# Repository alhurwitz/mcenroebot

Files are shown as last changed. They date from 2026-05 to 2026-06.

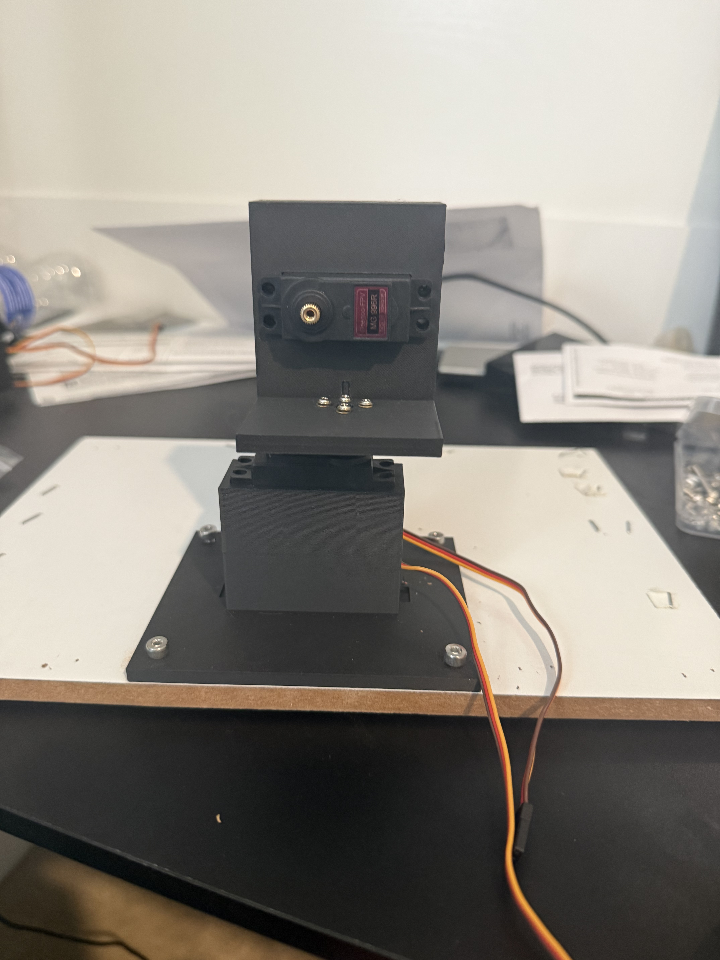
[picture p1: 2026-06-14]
docs/images/IMG_5126.jpg

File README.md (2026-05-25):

# McEnroe — Ping-Pong Robot (V2)

A hobby ping-pong robot. **V2** is the *aim-and-swat* phase: a 3-axis turret that orients a paddle at an incoming ball
and fires an open-loop swing to return it.

This repository holds the V2 control software. It runs against mocks on a laptop and on real hardware on a Raspberry Pi
4.

---

## How it works

A single webcam tracks the ball. Depth is recovered monocularly from the ball's apparent radius. A short rolling buffer
of observations is fit to a 3D ballistic trajectory, which predicts where (and when) the ball will cross the strike
plane. Two servos aim the paddle's sweep plane at that point; a brushless motor swings the paddle through it on a fixed
timing envelope.

```
 webcam ──► tracker ──► predictor ──► aim controller ──► servos (J1 yaw, J2 pitch)
                          │
                          └─────────► swing controller ──► BLDC (J3 swing)
```

### Hardware

| Part | Role |
|---|---|
| Raspberry Pi 4 (Bookworm, Python 3.11) | Deploy target |
| Adafruit PCA9685 16-channel PWM HAT | I²C `0x40` — pan=ch0, tilt=ch1, BLDC ESC=ch2 |
| 2× MG996R servos | J1 yaw, J2 pitch (paddle orientation) |
| A2212 1000 KV brushless motor + ESC | J3 paddle swing |
| 3S LiPo | BLDC supply |
| HAT 5V/3A PSU | Servo supply |
| Logitech webcam (`/dev/video0`) | Ball tracking (2D + monocular depth) |

### Coordinate frame

- **Origin:** J1 yaw axis, at J2 pitch pivot height.
- **+X** forward (toward the ball), **+Y** left (viewed from above), **+Z** up.
- Meters internally; degrees at servo I/O; seconds for time.

---

## Status

| Component | State |
|---|---|
| `aim/` (AimController, Position3D, ServoAngles, TurretGeometry) | ✅ Wave 1 |
| `clock/` (Clock, SystemClock, FakeClock) | ✅ Wave 1 |
| `camera/` (CameraIntrinsics, pixel_to_ray) | ✅ Wave 1 |
| `ball/` (BallObservation/State/Prediction, BallRadiusDepth) | ✅ Wave 1 |
| `drivers/servo/`, `drivers/bldc/` (Protocols + PCA9685 + Mocks) | ✅ Wave 1 |
| `predictor/` (TrajectoryPredictor, weighted ballistic fit) | ✅ Wave 2 |
| `swing/` (SwingProfile + SwingController, open-loop envelope) | ✅ Wave 2 |
| `calibrate/` (EscCalibrator one-shot routine) | ✅ Wave 2 |
| `coordinator/` (RallyCoordinator, full pipeline) | ✅ Wave 3 |
| Pi deployment | ⏳ Hardware bring-up |

See [`docs/implementation-plan.md`](docs/implementation-plan.md) for the wave-by-wave build schedule and
[`docs/V2_PLAN.md`](docs/V2_PLAN.md) for the original design.

---

## Quickstart (laptop development)

Prereqs: `uv` (replaces `pip`/`venv`).

```bash
uv sync                          # install runtime + dev deps into .venv
uv run pre-commit install --hook-type pre-commit --hook-type commit-msg
uv run pytest                    # run the full suite with coverage
uv run python -m mcenroebot.aim  # print aim-controller sanity demo
```

### Common commands

```bash
uv run pytest                                       # full suite (coverage runs automatically)
uv run pytest -q                                    # quiet
uv run pytest tests/test_aim.py::TestAimControllerCompute::test_directly_forward_gives_neutral_pose
uv run pytest -m unit                               # by marker: unit / integration / perf / adapter

uv run mypy src/                                    # strict, with pydantic plugin
uv run ruff check src/                              # lint
uv run ruff format src/                             # format

uv add <package>                                    # add a runtime dep (never edit pyproject.toml by hand)
uv add --dev <package>                              # dev-only
uv add --optional pi <package>                      # Pi-only optional extra
```

Pre-commit runs ruff (lint + format), mypy, detect-secrets, and commitizen on commit; pytest runs on **pre-push**.

---

## Pi deployment

Deferred until Wave 3 lands. The high-level steps:

```bash
# On the Pi
cd ~/mcenroebot
uv sync --extra pi               # pulls adafruit-blinka, pca9685, servokit
uv run python -m mcenroebot.calibrate   # one-shot ESC arming
uv run python -m mcenroebot.coordinator # rally loop against live webcam
```

The real Adafruit drivers are imported **lazily** inside the driver constructors so the package still imports on a Mac (
where those libraries aren't installed).

---

## Coding standards

These are the non-negotiable ones. See [`CLAUDE.md`](CLAUDE.md) for the full set.

- **OOP everywhere.** Public API is classes; no bare module-level functions.
- **Pydantic v2 frozen models** (`BaseModel` + `ConfigDict(frozen=True)`) for every value object. No `@dataclass`. Range
  checks via `@field_validator`. Pydantic constructors are **keyword-only** at every call site.
- **Hardware abstraction.** Every GPIO-touching driver has a `Protocol` interface and a paired `Mock<Name>Driver`.
  Higher-level code is tested against mocks only.
- **Type hints everywhere**; `mypy --strict` must pass.
- **Coverage ≥85%** (enforced); aim ≥95% on pure-math modules.

---

## Project layout

```
src/mcenroebot/        # package source (src-layout)
  aim.py               # implemented
  ...                  # see docs/implementation-plan.md for the rest
tests/                 # pytest, mirrors src/mcenroebot/ structure
docs/
  implementation-plan.md  # actionable wave-by-wave plan
  V2_PLAN.md              # original design + module specs
CLAUDE.md              # guidance for Claude Code sessions
pyproject.toml         # ruff, mypy strict, pytest config, coverage floor
```

---

## Gitflow

`main` ← `develop` ← `feature/*`. Conventional commits enforced by commitizen on commit-msg (`feat(scope):`,
`fix(scope):`, `refactor(scope):`, `test(scope):`, `chore:`, `docs:`).

Current state: `feature/aim` holds the aim module and pydantic v2 refactor; it will merge to `develop`, then
`feature/v2-control` will be cut for Waves 1–3.

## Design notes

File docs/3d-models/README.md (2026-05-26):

# McEnroe V2 — Arm Design ("Aim-and-Swat" Turret)

## The pivot

The original `PROJECT_PLAN.md` called for a dual-wheel ball launcher. This is the
arm-based alternative AJ asked for in V2: a real paddle on a swinging arm, aimed
by a 2-DOF turret. It's harder than a launcher but it's the McEnroe-y answer —
the robot actually *hits* the ball with a paddle instead of spitting it out of a
nozzle.

## Architecture

Three independent axes:

1. **Yaw** (J1) — base rotation. Aims the strike plane left/right.
2. **Pitch** (J2) — shoulder tilt. Aims up/down and sets approach angle.
3. **Swing** (J3) — fast paddle stroke. Open-loop, fired at a predicted T0.

J1 and J2 are MG996R metal-gear servos (slow-but-accurate aiming).
J3 is a brushless motor (A2212 1000KV from the existing BOM) — used for raw
swing speed, not closed-loop position control.

The control loop:
1. Camera tracks ball → trajectory predictor estimates contact point + time.
2. J1 + J2 move to point the strike plane at the predicted contact (settles
   well before T0).
3. At T0 − swing_latency, fire J3 throttle. Paddle sweeps through the plane.
4. Ball gets hit (in theory). Trash talk plays regardless of outcome.

## Why not a full 6-DOF arm

A real arm with closed-loop joint control needs harmonic drives or high-Kv
servos that cost more than the rest of the BOM combined. We don't have the
torque budget on hobby servos to drive a 0.25m arm fast enough. The compromise:
slow aiming + dumb fast swing.

## Honest limitation: paddle tip speed

A2212 1000KV at full throttle on 3S is ~11,000 RPM — way too fast for direct
drive on a paddle. At 10–20% throttle for ~150ms we get a 90° sweep with paddle
tip speed around 2–3 m/s. Recreational ping pong returns want 4–8 m/s tip
speed. So this first pass will probably hit the ball but won't drive it back
hard. That's fine — first iteration. Next iteration options:

- Gear down a higher-torque BLDC (or use a sensored brushless gimbal motor).
- Use a beefier outrunner (e.g. 2814 700KV) on a 4S pack.
- Add a torsion spring that pre-loads the arm and gets released by a servo.

## Parts (in this folder)

| File | What it is | Material | ~Print time |
|---|---|---|---|
| `01_base_plate.stl` | Bolts to a weighted base, mounts the yaw servo | PETG+ | ~2h |
| `02_yaw_bracket.stl` | Rides on yaw servo horn, mounts pitch servo | PETG+ | ~2h |
| `03_pitch_bracket.stl` | Rides on pitch servo horn, holds the BLDC + bearings | PETG+ | ~3h |
| `04_swing_arm.stl` | Bolts to BLDC shaft, holds the paddle clamp | PETG+ | ~1.5h |
| `05_paddle_clamp.stl` | Two halves that clamp a paddle blade | PLA matte | ~1h |

Use **PETG+** for everything load-bearing (PLA creeps under sustained torque).
Paddle clamp is fine in PLA since it's only loaded in compression.

## How parts mate

```
       [ paddle blade ]
              │
       [ paddle clamp ]   ← M3 × 4, pinches paddle blade
              │
       [ swing arm ]      ← M3 set-screw on BLDC shaft
              │
        ( A2212 BLDC )
              │
       [ pitch bracket ]  ← 608 bearings flank the motor
              │
        ( MG996R J2 )
              │
       [ yaw bracket ]
              │
        ( MG996R J1 )
              │
       [ base plate ]
              │
        weighted base (table-clamp, sandbag, anything heavy)
```

## Regenerating parts

All STLs are generated by `generate_parts.py` in this folder. Tweak constants
at the top, re-run, get new STLs:

```bash
cd 3d-models
python3 generate_parts.py
```

## Print settings (Bambu Studio, P2S)

- Nozzle: 0.4mm
- Layer height: 0.20mm (0.16 if you're feeling patient)
- Walls: 4 perimeters
- Infill: 40% gyroid for structural parts, 15% for paddle clamp
- Supports: tree, only on overhangs >55°. Most parts designed to print
  flat-side-down with no supports needed.
- Brim: 5mm on the swing arm (long thin part, wants to lift)

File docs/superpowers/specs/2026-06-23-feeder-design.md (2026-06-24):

# McEnroe V4 Feeder — Design Spec

Date: 2026-06-23
Status: Approved (brainstorming → implementation)
Branch: `feature/v4-feeder` (cut from `develop`)

This spec reconciles [`docs/V4_PLAN.md`](../../V4_PLAN.md) (mechanism source of truth) and
[`docs/v4-implementation-plan.md`](../../v4-implementation-plan.md) (build checklist) with the
**actual** state of the codebase as of 2026-06-23. Where the two plan docs disagree with reality,
this spec is authoritative for the software work.

---

## 1. Goal

Pivot McEnroe from an aim-and-swat / return-rally robot to a **feeder**: a spin/aim ball machine
that serves balls with controlled speed and spin to chosen court locations, with a closed recycle
loop (catch net → trough → auger → hopper → escapement → launch wheels).

**Explicitly out of scope** (the hard rally slice): incoming-ball 3D tracking, strike-plane
prediction, sub-100 ms timing. The feeder is a periodic scheduler driving actuators — not a
real-time vision control loop.

---

## 2. Codebase reconciliation (plan vs. reality)

A fresh inventory of `src/mcenroebot/` found the repo already contains the **entire V3 rally
stack**, not just the `aim/` slice the old CLAUDE.md describes. Findings that change the plan:

| Plan assumption | Reality | Resolution |
| --- | --- | --- |
| Reuse `aim/`, `clock/`, `camera/`, `drivers/servo/`, `drivers/bldc/` | All present and built | Reuse as-is |
| `drivers/bldc/` "extends `esc_arm`" | No `esc_arm`; ESC arming lives in `calibrate/EscCalibrator` (`calibrate/esc.py`) | `launch/` throttle helper + Wave 5 reuse `calibrate/EscCalibrator`; drop `esc_arm` references |
| Shelved: `predictor/`, `swing/`, `ball/`, `coordinator.RallyCoordinator` | All present and fully built | **Archive** to `_shelved/` (see §4) |
| Python floor `>=3.13`, reconcile to 3.11 before Pi | `pyproject.toml` already `requires-python = ">=3.11"` | **Resolved** — drop this open question |
| New: `launch/`, `drill/`, `drivers/feeder/`, `drivers/lift/`, `player/` | All correctly absent | Build per waves |
| Branch `feature/v4-feeder` from `develop` | Currently on `feature/v4`; `develop` exists but is behind | Cut `feature/v4-feeder` from `develop`, carry plan docs forward (see §3) |

Existing reused packages (do not modify): `aim/`, `clock/`, `camera/`, `calibrate/`,
`drivers/servo/`, `drivers/bldc/`.

---

## 3. Branch setup

- Cut `feature/v4-feeder` from `develop`.
- The V4 plan docs (`docs/V4_PLAN.md`, `docs/v4-implementation-plan.md`) and the untracked
  `docs/3d-models/generate_feeder_parts.py` currently live on `feature/v4`, not `develop`. Carry
  these files forward onto `feature/v4-feeder` so the plan travels with the work. The diff against
  `develop` is shown to the user before anything lands.
- Only feeder-relevant content is brought across; unrelated `feature/v4` commits are not merged.

---

## 4. Archive the V3 rally stack

Move the V3-only modules to `src/mcenroebot/_shelved/` (underscore prefix = clearly inactive, not
part of the public import surface). Verified safe: **nothing in the active/reused set imports the
V3-only set** — only `coordinator/rally.py` references `ball`/`predictor`/`swing`, and it moves too.

| Move from | Move to |
| --- | --- |
| `src/mcenroebot/ball/` | `src/mcenroebot/_shelved/ball/` |
| `src/mcenroebot/predictor/` | `src/mcenroebot/_shelved/predictor/` |
| `src/mcenroebot/swing/` | `src/mcenroebot/_shelved/swing/` |
| `src/mcenroebot/coordinator/rally.py` + `coordinator/__main__.py` | `src/mcenroebot/_shelved/rally/` |
| `tests/test_ball/`, `tests/test_predictor/`, `tests/test_swing/` | `tests/_shelved/...` |
| `tests/test_coordinator/test_rally.py` | `tests/_shelved/test_rally/...` |

Rules for the move:
- Rewrite internal imports within the moved set to `mcenroebot._shelved.*`. `ball/depth.py` keeps
  importing `mcenroebot.camera` (camera stays active; archive→active dependency is fine).
- **Tests move with their code and keep passing** so the 85% coverage floor holds across the move.
- `src/mcenroebot/__init__.py` keeps exporting only the aim symbols (already the case) — no
  `_shelved` symbols are re-exported at the top level.
- After the move, `coordinator/` holds only `__init__.py`, rewritten to export nothing (`__all__ =
  []`) until Wave 4 adds `FeederCoordinator`. The package is then ready to host `feeder.py`.
- `_shelved/__init__.py` documents the package as inactive V3 code, retained for reference.
- This is committed **first** on `feature/v4-feeder`, before any new feeder code, so the active
  surface is unambiguous. Phase gate: `uv run pytest` green, `uv run mypy src/` clean.

---

## 5. Conventions (mandatory — copy from `aim/` and `drivers/servo/`)

- Every component is a **package** (`__init__.py` + files split by responsibility: `protocol.py`,
  real impl, `mock.py`, `value_objects.py`, `controller.py`, `__main__.py` demo). Re-export the
  public API via `__init__.py`.
- Value objects are **pydantic v2 `BaseModel`, `frozen=True`**, keyword-only at all call sites.
  Range checks in `@field_validator`. Tests assert `ValidationError`, not `ValueError`.
- Controllers are **stateless apart from injected config**. Out-of-envelope → return `None`, don't raise.
- Every GPIO-touching driver: a `Protocol`, a real impl with Adafruit/GPIO libs **lazy-imported
  inside `__init__`**, and a `Mock<Name>Driver` that records calls. Higher layers test against
  mocks; real drivers are `@pytest.mark.integration`, skipped off-Pi.
- Conventional commits (`feat(scope):` …), one logical commit per package.
- Pi-only deps go in `[project.optional-dependencies] pi`, added via `uv add --optional pi`.

### Coordinate / spin conventions (used by `launch/`)

- Reuse the V2 frame: `+X` forward (toward the player), `+Y` left, `+Z` up. Meters internally,
  degrees for servo I/O, seconds for time.
- **Topspin > 0** (ball top rotates toward the player). Backspin < 0.
- `head_roll_deg`: rotation of the two-wheel head about the shot axis. `0°` = spin axis horizontal
  → pure top/backspin. `90°` = spin axis vertical → pure sidespin. General angle → mix.

---

## 6. Module architecture & waves

```
        clock/ (reuse)         camera/ (reuse, vision phase only)
           │                        │
           │                        ▼
           │                   player/ (NEW, Wave 6)
           │                        │
   ┌───────┴───────────┐            │
   ▼                   ▼            ▼
drivers/feeder/   drivers/lift/   drill/ ──── AimStrategy (Protocol)
   │                   │            │           ├─ FixedPatternStrategy (Wave 3)
   │                   │            │           └─ VisionPlacementStrategy (Wave 6)
   │                   │            ▼
   │                   │         launch/ (NEW, pure math)  aim/ (reuse)
   │                   │            │                         │
   └───────────────────┴───────┐    │   drivers/bldc/ (reuse) │  drivers/servo/ (reuse)
                               ▼    ▼            │            ▼            │
                          coordinator.FeederCoordinator (NEW) ────────────┘
```

### Wave 1 — `launch/` (pure math, no hardware) — **this session**

The analog of `aim/`. Built first; everything depends on its value objects. Target **≥95% coverage**.

| File | Contents |
| --- | --- |
| `value_objects.py` | `ShotSpec`, `WheelCommand`, `LaunchGeometry`, `ThrottleMap` |
| `controller.py` | `LaunchController` |
| `__main__.py` | demo: print `WheelCommand` for a few `ShotSpec`s |
| `__init__.py` | re-export public API |

```python
class ShotSpec(BaseModel):          # frozen
    speed_mps: float                # desired ball exit speed; > 0
    spin_rad_s: float               # signed magnitude; + = topspin at roll 0
    spin_axis_deg: float            # head roll: 0 = top/back, 90 = side; [0, 360)

class WheelCommand(BaseModel):      # frozen
    top_rpm: float                  # >= 0
    bottom_rpm: float               # >= 0
    head_roll_deg: float            # [0, 180] servo range (validate)

class LaunchGeometry(BaseModel):    # frozen; injected config, mirrors TurretGeometry
    wheel_diameter_m: float         # e.g. 0.055
    ball_radius_m: float = 0.02
    grip_efficiency: float = 0.85   # eta: ball speed / mean surface speed; calibrated
    spin_efficiency: float = 0.85   # eta_spin; calibrated
    max_wheel_rpm: float            # from no-load BLDC rpm at deploy voltage

class ThrottleMap(BaseModel):       # frozen; calibrated rpm <-> ESC throttle [0,1]
    rpm_at_full_throttle: float     # measured rpm at throttle = 1.0
    # linear v1 model: throttle = rpm / rpm_at_full_throttle, clamped [0,1]
```

`LaunchController.compute(spec) -> WheelCommand | None`:

```
mean_surface = speed_mps / grip_efficiency
diff_surface = 2 * ball_radius_m * spin_rad_s / spin_efficiency
u_top    = mean_surface + diff_surface / 2
u_bottom = mean_surface - diff_surface / 2
rpm(u)   = u * 60 / (pi * wheel_diameter_m)
top_rpm, bottom_rpm = rpm(u_top), rpm(u_bottom)
head_roll_deg = spin_axis_deg folded into [0, 180]   # 180° head symmetry
```

Return `None` (out of envelope) when `u_top < 0` or `u_bottom < 0` (spin too high for the speed),
or either rpm `> max_wheel_rpm`. Also provide
`LaunchController.throttles(cmd, throttle_map) -> tuple[float, float]` converting a `WheelCommand`
to two ESC throttles for the bldc layer.

Tests `tests/test_launch/`:
- Zero spin → `top_rpm == bottom_rpm == rpm(speed/grip_efficiency)`.
- Positive spin → `top_rpm > bottom_rpm`; negative → reversed.
- Round-trip: pick `(u_top, u_bottom)`, derive the `ShotSpec` they'd produce, confirm `compute`
  recovers those wheel speeds within `1e-6`.
- Spin too high for speed → `None` (not a negative rpm). rpm over `max_wheel_rpm` → `None`.
- `head_roll_deg` folds to `[0, 180]`; `WheelCommand` raises `ValidationError` outside it.
- `ThrottleMap` clamps to `[0, 1]`. Frozen-ness of all four value objects.

Commit: `feat(launch): add LaunchController + ShotSpec/WheelCommand/LaunchGeometry value objects`

### Wave 2 — `drivers/feeder/` + `drivers/lift/` (mock-tested, real gated)

- `drivers/feeder/` (escapement): `FeederDriver` Protocol (`set_rate(balls_per_min)`, `stop()`,
  `fire()` — v1 `fire()` raises `NotImplementedError`), `Pca9685FeederDriver` (CR servo on a
  PCA9685 channel; lazy `adafruit_servokit`; rate→throttle linear factor), `MockFeederDriver`.
- `drivers/lift/` (auger): `LiftDriver` Protocol (`set_duty([0,1])`, `off()`), `HopperSensor`
  Protocol (`is_full()`), `Pca9685LiftDriver` (PWM → MOSFET gate, lazy import), `MockLiftDriver`,
  `GpioHopperSensor` (lazy `RPi.GPIO`), `MockHopperSensor`.
- Tests: rate/duty monotonic + clamped; `stop()`/`off()` → 0; mocks record call order; lazy
  imports succeed off-Pi; real smoke tests `@integration`.
- Document the new PCA9685 channel map (two wheel ESCs, roll servo, CR-servo feeder) in `CLAUDE.md`,
  mirroring the existing `pan=ch0, tilt=ch1, ESC=ch2` line.

Commit: `feat(drivers): add feeder (escapement) and lift (auger) drivers with mocks`

### Wave 3 — `drill/` (no hardware)

- `AimStrategy` Protocol (`next_target(ctx) -> Position3D`), `Shot` value object (`spec`, `target`,
  `delay_s`), `FixedPatternStrategy` (patterns: `static`, `oscillate`, `random`, `figure8`; pure
  function of shot index + RNG seed), `Drill.shots(n) -> Iterator[Shot]` (stateless config +
  injected seeded RNG).
- Tests: targets within table bounds; fixed seed → identical sequence; cadence respected; figure-8
  quadrant order; frozen value objects.

Commit: `feat(drill): add Drill engine, AimStrategy Protocol, FixedPatternStrategy`

### Wave 4 — `coordinator/feeder.py` (no hardware)

`FeederCoordinator` (new file in `coordinator/`, must not import `_shelved.*`). Constructor injects
`drill`, `launch` + `launch_geometry` + `throttle_map`, `aim` (`AimController`), `servo` (pan/tilt),
`head_roll` servo, `wheel_top`/`wheel_bottom` BLDC, `feeder`, `lift`, `clock`, optional `hopper`.

`async run(n)` per shot: next `Shot` → `launch.compute` (skip+log if `None`) → `aim.compute`
(skip+log if unreachable) → command head-roll + pan/tilt + wheel throttles → settle → release ball
(`set_rate` v1) → run lift (`off()` if `hopper.is_full()`) → `clock.sleep(delay_s)`. On exit
(try/finally): wheels throttle 0, `feeder.stop()`, `lift.off()`.

Tests (mock everything + `FakeClock`): happy path ordered calls; `launch.compute None` skips shot;
`aim.compute None` skips shot; hopper full → `lift.off()`; clean shutdown on normal end and on
exception.

Phase gate: `uv run pytest` green, `uv run mypy src/` clean, coverage ≥85% (`launch/` ≥95%); a
simulated 100-shot drill issues correct ordered commands for 100/100 cases.

Commit: `feat(coordinator): add FeederCoordinator wiring drill -> launch + aim + feeder + lift`

### Wave 5 — calibration scripts + first live feed (hardware)

PEP-723 standalone scripts under `scripts/` (inline metadata, own deps — same pattern as
`scripts/calibrate_camera.py`):
- `scripts/calibrate_feeder.py` — sweep CR-servo throttle, count balls / 60 s, fit
  `balls_per_min ↔ throttle`.
- `scripts/calibrate_launch.py` — grid of `(top_rpm, bottom_rpm)`, measure landing distance (+spin
  if video available), back out `grip_efficiency`, `spin_efficiency`, `rpm_at_full_throttle`; writes
  JSON loadable via `LaunchGeometry.model_validate_json`.

Bring-up on the Pi (`uv sync --extra pi`): arm both ESCs via `calibrate/EscCalibrator` (once per
wheel) → run calibration scripts → run `FeederCoordinator` with a `static` `FixedPatternStrategy`
at low rpm.

Phase gate: 20 consecutive balls to a chosen spot at controlled speed, no jam/double-feed; auger
keeps hopper non-empty over a 5-minute run.

### Wave 6 — vision placement (optional, hardware)

`player/` package: `PlayerDetector` Protocol (`detect(frame) -> PlayerPosition | None`),
`PlayerPosition` value object (`side_offset_m`, `confidence`), `SimpleBlobDetector` (background
subtraction / contour centroid over the `camera/` frame source), `MockPlayerDetector`.
`drill.VisionPlacementStrategy` implements `AimStrategy`: aim next ball to the open side; low
confidence → fall back to a fixed pattern. Drops in behind the existing `AimStrategy` Protocol — no
change to `launch/`, `Drill`, or `FeederCoordinator` beyond injecting a different strategy.

Phase gate: player standing left → ≥80% of balls land right of center (and vice versa).

Commit: `feat(player): add PlayerDetector + VisionPlacementStrategy for open-court targeting`

---

## 7. Branching summary

```
develop
   └── feature/v4-feeder
         ├── (commit 1) archive V3 stack -> _shelved/ + carry V4 plan docs
         ├── (Wave 1) launch/
         ├── (Wave 2) drivers/feeder + drivers/lift
         ├── (Wave 3) drill/
         ├── (Wave 4) coordinator/feeder.py
         ├── (Wave 5) scripts/calibrate_feeder.py + scripts/calibrate_launch.py
         └── (Wave 6) player/ + VisionPlacementStrategy
```

Merge `feature/v4-feeder` → `develop` after Wave 5's phase gate (vision is a clean follow-up).

---

## 8. This session's deliverable

1. Write + commit this spec.
2. Cut `feature/v4-feeder` from `develop`, carry plan docs forward.
3. Archive the V3 stack to `_shelved/` (commit 1); verify suite green + mypy clean.
4. Implement **Wave 1 `launch/`** via TDD to its phase gate (tests green, mypy clean, ≥95% coverage).

Waves 2–6 are left for follow-up sessions.

### Status (updated 2026-06-24) — all waves code-complete

Every wave is implemented and committed on `feature/v4-feeder` via TDD:

| Wave | Module(s) | State |
| --- | --- | --- |
| 0 | archive V3 → `_shelved/` | done |
| 1 | `launch/` | done — 100% coverage |
| 2 | `drivers/feeder/`, `drivers/lift/` | done — mock-tested, real `@integration` |
| 3 | `drill/` | done — 100% coverage |
| 4 | `coordinator/feeder.py` | done — 100% coverage, 100-shot sim passes |
| 5 | `scripts/calibrate_feeder.py`, `calibrate_launch.py` | code-complete; **live-feed gate needs Pi hardware** |
| 6 | `player/`, `drill.VisionPlacementStrategy` | done — 100% coverage; **live gate needs Pi hardware** |

Full suite: **473 passed, 8 skipped** (Pi-only `@integration`), **mypy clean**, **ruff clean**,
project coverage **96.48%** (`launch/` 100%). Remaining work is hardware-only: run the Wave 5
calibration + first-live-feed gate and the Wave 6 ≥80%-to-open-side gate on the Pi, then merge
`feature/v4-feeder` → `develop`.

---

## 9. Open questions / risks (carried forward)

- **ESC throttle → rpm is nonlinear under load.** The v1 linear `ThrottleMap` is a placeholder;
  upgrade `calibrate_launch.py` to a 2nd-order/lookup curve if launch speed is inconsistent.
- **CR-servo feed rate drifts** (battery sag, load). If per-shot timing matters for vision sync,
  add the index endstop (`V4_PLAN.md §1`) and implement `FeederDriver.fire()` for a real
  `ball_fired` event.
- **Two ESCs on one PCA9685.** Confirm channel assignment and shared-ground/power budget before
  wiring; document the channel map in `CLAUDE.md`.
- **Head-roll servo channel.** Decide whether roll shares the servo driver instance (extra channel)
  or a second instance; reflect in `FeederCoordinator`'s constructor.

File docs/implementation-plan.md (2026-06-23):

# McEnroe V2 — Implementation Plan

Actionable, wave-by-wave execution plan derived from [`V2_PLAN.md`](V2_PLAN.md). Read V2_PLAN.md first for the design rationale and module specifications; this document is the build checklist.

---

## 0. Snapshot

| Item | Value |
| --- | --- |
| Working directory | `/Users/alberthurwitz/Projects/mcenroebot` |
| Package | `src/mcenroebot/` (src-layout) |
| Tests | `tests/` |
| Python | ≥3.11 (per `pyproject.toml`; matches the Pi/Bookworm 3.11 deploy target) |
| Dep manager | `uv` (never hand-edit `pyproject.toml` deps) |
| Coverage floor | 85% (aim ≥95% on pure-math modules) |
| Current branch | `feature/v2-control` |
| Done | **All four waves complete.** `aim/`, `clock/`, `camera/`, `ball/`, `drivers/{servo,bldc}/`, `predictor/`, `swing/`, `calibrate/`, `coordinator/` packages all landed. **343 tests pass**, 6 correctly skipped (pi-only), 94%+ project coverage |
| Next | Open PR `feature/v2-control` → `develop`; Pi deployment after merge |
| Structure | Each component is a **package** under `src/mcenroebot/<name>/` (`__init__.py`, split files by responsibility); tests mirror at `tests/test_<name>/test_<concern>.py` |

### Module dependency graph

```
                 ┌──────────────┐
                 │   clock.py   │  (no deps)
                 └──────┬───────┘
                        │
              ┌─────────┴──────────┐
              ▼                    ▼
       ┌────────────┐       ┌─────────────┐
       │   ball.py  │◄──────│  camera.py  │
       └─────┬──────┘       └─────────────┘
             │
             ▼
     ┌────────────────┐    ┌──────────────────┐
     │ predictor.py   │    │ drivers/servo.py │
     └───────┬────────┘    │ drivers/bldc.py  │
             │             └────────┬─────────┘
             │                      │
             │     ┌────────────────┤
             │     ▼                ▼
             │  ┌──────────┐   ┌──────────────┐
             │  │ swing.py │   │ calibrate.py │
             │  └─────┬────┘   └──────────────┘
             │        │
             ▼        ▼
        ┌──────────────────┐    ┌────────────┐
        │  coordinator.py  │───►│   aim.py   │ (already exists)
        └──────────────────┘    └────────────┘
```

---

## 1. Wave 0 — verify the pydantic refactor (✅ done)

The pydantic v2 migration of `aim.py` and `tests/test_aim.py` is committed (`632a8e9`). Before starting Wave 1, run the gates once:

```bash
uv sync
uv run pytest -q          # all 30 tests pass, coverage ≥85%
uv run mypy src/          # clean under strict
uv run ruff check src/    # clean
```

---

## 2. Wave 1 — foundation modules (sequential, with subagent review)

Each module is a **package** under `src/mcenroebot/<name>/` (`__init__.py` + split files), tested via mirror layout under `tests/test_<name>/`.

| # | Package | Status | Public surface | Tests required |
| --- | --- | --- | --- | --- |
| 1A | `aim/` | ✅ done (`56950c4`) | `AimController`, `Position3D`, `ServoAngles`, `TurretGeometry` split into `value_objects.py` + `controller.py` | n/a — already covered |
| 1B | `clock/` | ✅ done (`56950c4`) | `Clock(Protocol)`, `SystemClock`, `FakeClock` split into `protocol.py`, `system.py`, `fake.py` | Protocol compliance; monotonicity; `FakeClock.sleep` non-blocking; `SystemClock.sleep` real-time; negative durations raise `ValueError` |
| 1C | `camera/` | ✅ done (`3698c8c`) | `CameraIntrinsics` + `pixel_to_ray(u, v)` in `intrinsics.py` | Round-trip a known projection; default distortion is zero; `ValidationError` on negative focal length |
| 1D | `ball/` | ✅ done (`9b305d5`) | `BallObservation`, `BallState`, `StrikePrediction`, `PixelObservation` in `value_objects.py`; `DepthEstimator(Protocol)`, `BallRadiusDepthEstimator`, stubs in `depth.py` | Round-trip known geometry through `BallRadiusDepthEstimator`; frozen-ness of all models; `confidence` ∈ `[0, 1]`; `ValidationError` on negative `radius_px` |
| 1E | `drivers/servo/`, `drivers/bldc/` | ✅ done (`b9a9fb0` deps, `547c1be` code) | `ServoDriver(Protocol)` + `PCA9685ServoDriver` (lazy `adafruit_servokit` import) + `MockServoDriver`; `BLDCDriver(Protocol)` + `PCA9685BLDCDriver` (throttle 0→1000 µs, 1→2000 µs) + `MockBLDCDriver` | Mock drivers record calls in order; real driver doesn't require Adafruit libs at import-time; real-driver smoke tests are `@pytest.mark.integration` and skipped off-Pi; throttle outside `[0, 1]` rejected; `set_throttle` pre-arm raises `RuntimeError` |

**Commits** (one per package):
```
feat(camera): add pinhole CameraIntrinsics model
feat(ball): add BallObservation, BallState, StrikePrediction, DepthEstimator
chore(deps): add pi optional extra (adafruit blinka + pca9685 + servokit)
feat(drivers): add ServoDriver + BLDCDriver protocols, real + mock impls
```

Pi-only dependencies (`adafruit-blinka`, `adafruit-circuitpython-pca9685`, `adafruit-circuitpython-servokit`) live in `[project.optional-dependencies] pi = [...]` added via `uv add --optional pi <pkg>`. Real drivers import Adafruit libs **lazily inside `__init__`** so the package still imports cleanly on a Mac without the extra installed.

### End-of-Wave-1 housekeeping

1. `uv run pytest`, `uv run mypy src/`, `uv run ruff check src/` — all green.
2. Merge to `develop`:
   ```bash
   git checkout develop
   git merge --no-ff feature/aim
   git push origin develop
   ```
3. Cut the next feature branch:
   ```bash
   git checkout -b feature/v2-control
   ```

---

## 3. Wave 2 — modules that depend on Wave 1 (all ✅ done)

| # | Package | Status | Notes |
| --- | --- | --- | --- |
| 2A | `predictor/` | ✅ done (`a8a0c4e`) | `TrajectoryPredictor` with per-axis weighted least-squares fit (gravity on RHS for Z), exponential-decay weighting, confidence ∈ [0, 1], 47 tests covering recovery, gating, moving-away, weighting bias |
| 2B | `swing/` | ✅ done (`95d1381`) | `SwingProfile` (frozen, validated bounds) + `SwingController` (async context manager, lazy arm, tick-cadence envelope sampling, always ends at throttle 0, disarms on exit even when fire raises) |
| 2C | `calibrate/` | ✅ done (`0847c39`) | `EscCalibrator` one-shot routine: prompt → set_throttle(1.0) → prompt → settle → set_throttle(0.0) → prompt → settle → disarm; try/finally guarantees disarm on KeyboardInterrupt |

---

## 4. Wave 3 — integration (✅ done)

| # | Package | Status | Notes |
| --- | --- | --- | --- |
| 3 | `coordinator/` | ✅ done (`2f3ba26`) | `RallyCoordinator` wires `observations → TrajectoryPredictor → AimController → ServoDriver → SwingController`. Lazy swing arming on first reachable strike prediction. `rearm_min_interval_s` enforces one-fire-per-arc. 18 integration tests with mocks + `FakeClock`. |

### Final gates (all green)

```bash
uv run pytest          # 343 passed, 6 skipped (pi-only), 94%+ project coverage
```

Pre-commit hooks (ruff, ruff-format, mypy strict, detect-secrets, commitizen, pytest) pass on every commit.

Open PR `feature/v2-control` → `develop`.

---

## 5. Pi deployment (post-Wave 3)

1. SSH/SFTP repo to `~/mcenroebot/` on the Pi.
2. `uv sync --extra pi`
3. Wire hardware: PCA9685 HAT at I2C `0x40`, servos on ch0/ch1, ESC signal on ch2, 3S LiPo to BLDC, HAT 5V/3A PSU to servos.
4. `uv run python -m mcenroebot.calibrate` once to arm the ESC.
5. Run the coordinator against the live webcam feed.

---

## 6. Open questions / risks

These are flagged in `V2_PLAN.md §8`; they must be resolved before the system runs end-to-end:

- **Camera intrinsics are unknown.** `BallRadiusDepthEstimator` needs real `CameraIntrinsics`. ✅ `scripts/calibrate_camera.py` exists (PEP 723 inline-metadata standalone script — declares its own opencv/numpy/pydantic deps so it doesn't pollute the runtime dependency tree). Two subcommands: `capture` (live webcam preview, SPACE-to-save when a checkerboard is detected) and `solve` (run `cv2.calibrateCamera` over saved frames, write a JSON file that loads directly via `CameraIntrinsics.model_validate_json`). Print a 9×6 checkerboard at 25mm squares, capture 15–25 frames at varied angles, run `solve`. Synthetic smoke test recovers fx/fy/cx/cy to <0.5 px on noise-free projections. Actual calibration still needs to be run against AJ's webcam.
- **Strike plane location.** Defaults to `x = arm_length_m` (0.20 m forward). Confirm against the physical mount once the turret is assembled.
- **Swing latency** (`swing_latency_s = 0.05` s) is a guess. First hardware-in-loop test must measure actual mechanical latency and update the default.
- **Audio / trash-talk** is out of scope for V2. `RallyCoordinator` should expose a hook for a future `audio.py`.

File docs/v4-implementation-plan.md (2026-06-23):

# McEnroe V4 (Feeder) — Implementation Plan

Actionable, wave-by-wave code plan for the **feeder** — the spin/aim ball machine with a closed
recycle loop. Derived from [`V4_PLAN.md`](V4_PLAN.md) (design source of truth — read it first for
mechanism rationale, dimensions, and BOM). This document is the build checklist for the software.

The feeder is a *feeder*, not a return-rally robot: it serves balls with controlled speed/spin to
chosen court locations, the human returns into a catch net, and an auger recycles balls to the
hopper. There is **no incoming-ball tracking, no strike-plane prediction, no sub-100 ms timing**.
The V3 rally path (`predictor/`, `swing/`, `RallyCoordinator`) is untouched and unused here.

---

## 0. Snapshot

| Item | Value |
| --- | --- |
| Working directory | `/Users/alberthurwitz/Projects/mcenroebot` |
| Package | `src/mcenroebot/` (src-layout) |
| Tests | `tests/` mirror at `tests/test_<name>/test_<concern>.py` |
| Python | match `pyproject.toml` (≥3.13 floor; Pi/Bookworm 3.11 reconcile is a pre-deploy task, not a code task) |
| Dep manager | `uv` (`uv add` / `uv add --optional pi` — never hand-edit deps) |
| Coverage floor | 85% project; **≥95% on pure-math (`launch/`)** |
| Branch | cut `feature/v4-feeder` from `develop` after V2 has merged |
| Reuses unchanged | `clock/`, `aim/`, `drivers/servo/`, `drivers/bldc/`, `camera/` (vision phase only) |
| Shelved (do not import) | `predictor/`, `swing/`, `ball/`, `coordinator.RallyCoordinator` |

### Conventions (mandatory — copy from `aim/` and `drivers/servo/`)

- Every component is a **package** (`__init__.py` + files split by responsibility: `protocol.py`,
  real impl, `mock.py`, `value_objects.py`, `controller.py`, `__main__.py` demo). Re-export public
  API via `__init__.py`.
- Value objects are **pydantic v2 `BaseModel`, `frozen=True`**, keyword-only at call sites. Range
  checks in `@field_validator`. Tests assert `ValidationError`, not `ValueError`.
- Controllers are **stateless apart from injected config**. Out-of-envelope → return `None`, don't raise.
- Every GPIO-touching driver: a `Protocol`, a real impl with Adafruit/GPIO libs **lazy-imported
  inside `__init__`**, and a `Mock<Name>Driver` that records calls. Higher layers test against mocks.
  Real drivers are `@pytest.mark.integration`, skipped off-Pi.
- Conventional commits (`feat(scope):`…), one logical commit per package.

### Coordinate system / spin sign conventions (used by `launch/`)

- Reuse V2 frame: `+X` forward (toward the player), `+Y` left, `+Z` up. Meters, degrees for servo I/O.
- **Topspin > 0** (ball top rotates toward the player). Backspin < 0.
- `head_roll_deg`: rotation of the two-wheel head about the shot axis. `0°` = spin axis horizontal
  → pure top/backspin. `90°` = spin axis vertical → pure sidespin. General angle → mix.

---

## 1. Module dependency graph

```
        clock/ (reuse)         camera/ (reuse, vision phase only)
           │                        │
           │                        ▼
           │                   player/ (NEW, Phase B)
           │                        │
   ┌───────┴───────────┐            │
   ▼                   ▼            ▼
drivers/feeder/   drivers/lift/   drill/ ──── AimStrategy (Protocol)
   │                   │            │           ├─ FixedPatternStrategy (Phase A)
   │                   │            │           └─ VisionPlacementStrategy (Phase B)
   │                   │            ▼
   │                   │         launch/ (NEW, pure math)  aim/ (reuse)
   │                   │            │                         │
   └───────────────────┴───────┐    │   drivers/bldc/ (reuse) │  drivers/servo/ (reuse)
                               ▼    ▼            │            ▼            │
                          coordinator.FeederCoordinator (NEW) ────────────┘
```

---

## 2. Wave 1 — pure-math launch controller (no hardware)

The analog of `aim/`. Build and fully cover this first; everything else depends on its value objects.

### `launch/`

| File | Contents |
| --- | --- |
| `value_objects.py` | `ShotSpec`, `WheelCommand`, `LaunchGeometry`, `ThrottleMap` |
| `controller.py` | `LaunchController` |
| `__main__.py` | demo: print `WheelCommand` for a few `ShotSpec`s |

```python
class ShotSpec(BaseModel):
    model_config = ConfigDict(frozen=True)
    speed_mps: float            # desired ball exit speed; > 0
    spin_rad_s: float           # signed magnitude of spin; + = topspin at roll 0
    spin_axis_deg: float        # head roll: 0 = top/back, 90 = side; [0, 360)

class WheelCommand(BaseModel):
    model_config = ConfigDict(frozen=True)
    top_rpm: float              # >= 0
    bottom_rpm: float           # >= 0
    head_roll_deg: float        # [0, 180] servo range (validate)

class LaunchGeometry(BaseModel):     # injected config, mirrors TurretGeometry
    model_config = ConfigDict(frozen=True)
    wheel_diameter_m: float          # e.g. 0.055
    ball_radius_m: float = 0.02
    grip_efficiency: float = 0.85    # eta: ball speed / mean surface speed; calibrated
    spin_efficiency: float = 0.85    # eta_spin; calibrated
    max_wheel_rpm: float             # from no-load BLDC rpm at the deploy voltage

class ThrottleMap(BaseModel):        # calibrated rpm <-> ESC throttle [0,1]
    model_config = ConfigDict(frozen=True)
    rpm_at_full_throttle: float      # measured no-load (or loaded) rpm at throttle = 1.0
    # linear model for v1: throttle = rpm / rpm_at_full_throttle, clamped [0,1]
```

`LaunchController.compute(spec) -> WheelCommand | None`

Math (two counter-rotating wheels; ball gripped between them):

```
mean_surface = speed_mps / grip_efficiency           # m/s
diff_surface = 2 * ball_radius_m * spin_rad_s / spin_efficiency
u_top    = mean_surface + diff_surface / 2           # m/s
u_bottom = mean_surface - diff_surface / 2
rpm(u)   = u * 60 / (pi * wheel_diameter_m)
top_rpm, bottom_rpm = rpm(u_top), rpm(u_bottom)
head_roll_deg = spin_axis_deg folded into [0, 180]   # 180 head symmetry
```

Return `None` (out of envelope) when `u_top < 0` or `u_bottom < 0` (spin too high for the speed) or
either rpm `> max_wheel_rpm`. Provide `LaunchController.throttles(cmd, throttle_map) -> tuple[float, float]`
helper that converts a `WheelCommand` to two ESC throttles for the bldc layer.

### Tests `tests/test_launch/`

- Zero spin → `top_rpm == bottom_rpm`; both equal `rpm(speed/grip_efficiency)`.
- Positive spin → `top_rpm > bottom_rpm`; negative → reversed.
- Round-trip: pick `(u_top, u_bottom)`, derive the `ShotSpec` they'd produce, confirm `compute`
  recovers those wheel speeds within 1e-6.
- Spin too high for speed → `compute` returns `None` (not a negative rpm).
- rpm over `max_wheel_rpm` → `None`.
- `head_roll_deg` folds to `[0, 180]`; `WheelCommand` raises `ValidationError` outside it.
- `ThrottleMap` clamps to `[0, 1]`.
- Frozen-ness of all four value objects. **Target ≥95% coverage.**

Commit: `feat(launch): add LaunchController + ShotSpec/WheelCommand/LaunchGeometry value objects`

---

## 3. Wave 2 — actuator drivers (mock-tested, real gated)

### `drivers/feeder/` (escapement)

```python
class FeederDriver(Protocol):
    def set_rate(self, balls_per_min: float) -> None: ...   # v1 continuous CR servo
    def stop(self) -> None: ...
    def fire(self) -> None: ...                             # index-upgrade path; v1 raises NotImplementedError

class Pca9685FeederDriver:   # continuous-rotation servo on a PCA9685 channel
    """Lazy adafruit_servokit import in __init__. Maps balls_per_min -> continuous_servo
    throttle [-1, 1] via a calibrated linear factor (see scripts/calibrate_feeder.py)."""

class MockFeederDriver:      # records (set_rate / stop / fire) calls in order
```

Tests: rate→throttle monotonic and clamped; `stop()` sets throttle 0; mock records order; real
driver imports cleanly without adafruit installed (lazy import); real smoke test `@integration`.

### `drivers/lift/` (auger)

```python
class LiftDriver(Protocol):
    def set_duty(self, fraction: float) -> None: ...   # [0,1] PWM to MOSFET/L298N enable
    def off(self) -> None: ...

class HopperSensor(Protocol):
    def is_full(self) -> bool: ...

class Pca9685LiftDriver: ...        # PWM channel -> MOSFET gate (single direction); lazy import
class MockLiftDriver: ...           # records duty calls
class GpioHopperSensor: ...         # reads a GPIO endstop; lazy RPi.GPIO import
class MockHopperSensor: ...         # programmable is_full() for tests
```

Tests: duty clamped `[0,1]`; `off()` → duty 0; mock records; sensor mock toggles; real `@integration`.

Commit: `feat(drivers): add feeder (escapement) and lift (auger) drivers with mocks`

---

## 4. Wave 3 — drill engine + aim strategy (no hardware)

### `drill/`

```python
class AimStrategy(Protocol):
    def next_target(self, ctx: DrillContext) -> Position3D: ...   # court location to aim at

class Shot(BaseModel):
    model_config = ConfigDict(frozen=True)
    spec: ShotSpec
    target: Position3D            # reuse aim/.Position3D
    delay_s: float                # time until this shot fires (cadence)

class FixedPatternStrategy:       # Phase A — no vision
    """patterns: 'static', 'oscillate' (L/R baseline), 'random', 'figure8'.
    Pure function of shot index + RNG seed; fully deterministic under a fixed seed."""

class Drill:
    """Combines a spin/speed pattern + an AimStrategy + cadence into an iterator of Shot.
    Stateless config + an injected RNG (seed for reproducible tests)."""
    def shots(self, n: int | None = None) -> Iterator[Shot]: ...
```

Tests: each pattern produces targets inside the table bounds; fixed seed → identical Shot sequence
(determinism); cadence respected; figure-8 visits the expected quadrant order; `Shot`/`ShotSpec`
frozen. No hardware, pure logic — aim high coverage.

Commit: `feat(drill): add Drill engine, AimStrategy Protocol, FixedPatternStrategy`

---

## 5. Wave 4 — coordinator integration (no hardware)

Add a **new** `FeederCoordinator` alongside the existing `RallyCoordinator` in `coordinator/`
(new file `coordinator/feeder.py`). It must not import `predictor`/`swing`.

```python
class FeederCoordinator:
    def __init__(
        self,
        drill: Drill,
        launch: LaunchController,
        launch_geometry: LaunchGeometry,
        throttle_map: ThrottleMap,
        aim: AimController,                  # reuse: target Position3D -> ServoAngles
        servo: ServoDriver,                  # pan + tilt
        head_roll: ServoDriver,              # roll servo (or same driver, different channel)
        wheel_top: BLDCDriver,
        wheel_bottom: BLDCDriver,
        feeder: FeederDriver,
        lift: LiftDriver,
        clock: Clock,
        hopper: HopperSensor | None = None,
    ): ...

    async def run(self, n: int | None = None) -> None:
        """Periodic, NOT real-time. Per shot:
           1. ctx-> drill.next Shot
           2. launch.compute(spec) -> WheelCommand (skip + log if None)
           3. aim.compute(target)  -> ServoAngles (skip + log if None / unreachable)
           4. command head_roll, pan/tilt servos; set wheel ESC throttles via throttle_map
           5. let wheels + aim settle (settle_s)
           6. feeder.set_rate (v1) / feeder.fire (index upgrade) to release the ball
           7. run lift: duty on; if hopper and hopper.is_full(): lift.off()
           8. clock.sleep(shot.delay_s)
        On exit: wheels throttle 0, feeder.stop(), lift.off()."""
```

Tests `tests/test_coordinator/test_feeder.py` (mock everything + `FakeClock`):
- Happy path: N shots → expected ordered driver calls (aim set, then wheels, then settle, then feed).
- `launch.compute` → `None`: that shot is skipped, no wheel/feed calls, loop continues.
- `aim.compute` → `None` (unreachable target): shot skipped.
- Hopper full → `lift.off()` called; not full → lift runs.
- Clean shutdown: on normal end and on exception, wheels at 0, feeder stopped, lift off (try/finally).

Commit: `feat(coordinator): add FeederCoordinator wiring drill -> launch + aim + feeder + lift`

**Phase gate (Wave 4):** `uv run pytest` green, `uv run mypy src/` clean, coverage ≥85%
(`launch/` ≥95%). A simulated 100-shot drill issues correct, ordered commands for 100/100 cases.

---

## 6. Wave 5 — calibration scripts + first live feed (hardware)

Standalone PEP 723 scripts under `scripts/` (inline metadata, own deps — same pattern as
`scripts/calibrate_camera.py`; do not pollute runtime deps).

- `scripts/calibrate_feeder.py` — sweep CR-servo throttle, count balls over 60 s, fit the
  `balls_per_min ↔ throttle` factor for `Pca9685FeederDriver`.
- `scripts/calibrate_launch.py` — for a grid of `(top_rpm, bottom_rpm)`, fire and measure landing
  distance (and, if available, video-measured spin); back out `grip_efficiency`, `spin_efficiency`,
  and `ThrottleMap.rpm_at_full_throttle`. Writes a JSON loadable via `LaunchGeometry.model_validate_json`.

Bring-up order on the Pi (`uv sync --extra pi`):
1. Arm both ESCs (reuse `calibrate/EscCalibrator`, once per wheel).
2. `calibrate_feeder.py` → feeder factor. `calibrate_launch.py` → launch constants.
3. Run `FeederCoordinator` with a `FixedPatternStrategy` `static` drill (one fixed target) at low rpm.

**Phase gate (Wave 5):** machine serves 20 consecutive balls to a chosen spot at a controlled
speed without jam or double-feed; auger keeps the hopper non-empty over a 5-minute run. **Champagne.**

---

## 7. Wave 6 — vision placement (optional, hardware; the camera's role)

Only after Wave 5 is solid. This is the *easy* slice of vision (player/court detection in the
forgiving 1–2 s feed interval), not incoming-ball 3D prediction.

### `player/` (NEW)

```python
class PlayerDetector(Protocol):
    def detect(self, frame: NDArray) -> PlayerPosition | None: ...   # where the human is

class PlayerPosition(BaseModel):
    model_config = ConfigDict(frozen=True)
    side_offset_m: float      # left/right of center along the player's baseline
    confidence: float         # [0,1]

class SimpleBlobDetector:     # background subtraction / contour centroid; reuse camera/ frame source
class MockPlayerDetector: ...
```

### `drill.VisionPlacementStrategy`

Implements `AimStrategy`: read latest `PlayerPosition`, aim the next ball to the *open* side (or a
configured "attack the weakness" target). Drops in behind the existing `AimStrategy` Protocol — no
change to `launch/`, `drill.Drill`, or `FeederCoordinator` beyond injecting a different strategy.

Tests: open-side selection given a player offset; low confidence → fall back to a fixed pattern;
mock detector drives deterministic targets.

Commit: `feat(player): add PlayerDetector + VisionPlacementStrategy for open-court targeting`

**Phase gate (Wave 6):** with the player standing left, ≥80% of served balls land right of center
(and vice versa), at recreational pace.

---

## 8. Branching

```
develop (V2 complete; V3 lives on its own feature branches)
   └── feature/v4-feeder
         ├── (Wave 1) launch/
         ├── (Wave 2) drivers/feeder + drivers/lift
         ├── (Wave 3) drill/
         ├── (Wave 4) coordinator/feeder.py
         ├── (Wave 5) scripts/calibrate_feeder.py + scripts/calibrate_launch.py
         └── (Wave 6) player/ + VisionPlacementStrategy
```

Merge `feature/v4-feeder` → `develop` after Wave 5's phase gate (vision is a clean follow-up).

---

## 9. Open questions / risks

- **ESC throttle → rpm is nonlinear under load.** The v1 linear `ThrottleMap` is a placeholder;
  if launch speed is inconsistent, upgrade `calibrate_launch.py` to fit a 2nd-order or lookup curve.
- **CR-servo feed rate drifts** (battery sag, load). If per-shot timing matters for vision sync,
  add the index endstop (`V4_PLAN.md §1`) and implement `FeederDriver.fire()` for a real
  `ball_fired` event instead of open-loop rate.
- **Two ESCs on one PCA9685.** Confirm channel assignment and shared-ground/power budget before
  wiring; document the channel map in `CLAUDE.md` like the V2 `pan=ch0, tilt=ch1, ESC=ch2` line.
- **Python floor drift.** `pyproject.toml` says ≥3.13, `implementation-plan.md` says ≥3.11, Pi is
  Bookworm 3.11. Reconcile before Pi deploy; not a blocker for Waves 1–4 (dev machine).
- **Head-roll servo channel.** Decide whether roll shares the servo driver instance (extra channel)
  or a second instance; reflect in `FeederCoordinator`'s constructor.

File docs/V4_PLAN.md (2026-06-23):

# FEEDER_PLAN.md

Source of truth for the **feeder** architecture — the spin/aim ball machine with a closed
recycle loop. Supersedes the aim-and-swat turret for this build direction. The aim math,
servo conventions, and driver patterns from `V2_PLAN.md` carry over; the rally/strike-plane
prediction path (`trajectory`, `predictor`, `swing`) is shelved, not deleted.

Ball reference: 40 mm diameter, ~2.7 g, ABS. All clearances below assume a 40 mm ball.

---

## 1. Escapement (single-ball feeder)

Meters loose balls from the hopper into the launch throat, one at a time, jam-free.

### Mechanism

Single-pocket **indexing disk** at the hopper floor. One cylindrical pocket scoops a ball at
the load station, carries it ~180°, drops it into the launch throat at discharge. The disk's
solid top face blocks the hopper outlet everywhere except the pocket — so single-ball metering
is **geometric, not timed**. One pocket = one ball per revolution. Fire rate = disk rpm.

### Dimensions

| Part | Value | Notes |
|---|---|---|
| Disk OD | 90 mm | |
| Pocket bore | 42 mm | ball + 2 mm clearance |
| Pocket depth | 22 mm | seats ball, releases clean |
| Hopper cone half-angle | ≥ 60° from horizontal | steep — 40 mm balls bridge easily |
| Disk shaft bearing | 608 (22 OD / 8 bore) | press-fit printed seat |
| Pocket lip | 1 mm chamfer | prevents pinch at load |

### Actuator — v1 vs upgrade

- **v1 (recommended): continuous-rotation servo, fixed rate.** Plugs into the existing PCA9685
  exactly like the aim servos — no new driver concept, no stepper board, no soldering. Run at
  constant speed → constant feed rate (set 40–60 balls/min). The machine just spits periodically,
  like a cheap commercial feeder. Sensorless.
- **Upgrade (only if per-ball timing matters): add one index endstop.** A 3-pin optical endstop
  (3D-printer style, solderless Dupont) trips once per revolution → a real `ball_fired` event.
  Needed only if you want vision placement tightly phased to each shot. Defer.

### Failure modes

- **Hopper bridging** (balls arch over the outlet, feed stops): steep cone + a stir-finger on the
  disk shaft sweeping the hopper floor.
- **Double-feed**: a fixed "roof" over the load station, gap = one ball height, so only one seats.
- **Edge pinch**: keep ≥ 2 mm pocket clearance + lip chamfer.

### Print

Disk face-down on smooth plate (or sand the bearing face), PETG for wear. Hopper as a cone,
printed in sections if it exceeds bed.

---

## 2. Auger lift (trough → hopper)

Returns balls from the floor-level catch trough up to the hopper. One motor, continuous, slow.

### Mechanism

Helical screw inside a close-fitting tube (Archimedes screw). Balls sit between flights and ride
up as the screw turns; the flight below each ball prevents fallback. **Inclined ~50–60°, not
vertical** — gravity seats balls into the flights at entry and stops rattle/fallback.

### Dimensions

| Part | Value | Notes |
|---|---|---|
| Tube ID | 46 mm | ball + 3 mm each side |
| Screw OD | 44 mm | 1 mm gap to tube |
| Screw core rod | 8 mm steel | smooth rod, cheap; screw segments key onto it |
| Flight pitch | 55 mm | > ball dia, so one ball fits per pitch |
| Incline | 50–60° | forgiving entry, fallback-resistant |
| Lift height | hopper inlet − trough | likely 700–900 mm |

### Print (the one fussy part)

Bed is ~256 mm, lift is ~800 mm → **tube + screw print in ~4 sections.**
- Screw: short **keyed segments stacked on the 8 mm steel rod** — do *not* try to print one long
  helix. Each segment prints helix-axis along Z with supports; sand the joints flush (a step at a
  joint catches balls).
- Tube: 4 slip-fit sections + printed external clamps/spine to hold them collinear. A non-straight
  tube jams.
- PETG (the screw rubs).

### Motor

12 V DC gearmotor, ~60 rpm, moderate torque. On/off (PWM optional if too fast). No precision
needed. Drive via a solderless MOSFET module or L298N off a 12 V buck from the LiPo.

### Throughput / why "no refill" works

The lift only has to beat **average** fire rate, not peak. The buffer hopper absorbs the mismatch:

- Hopper buffer: **~80 balls ≈ 4.5 L** (cone ~200 mm dia × 250 mm).
- At 55 mm pitch × 60 rpm the screw advances balls ~3 m/min — comfortably above a 40–60 balls/min
  feed rate, so the hopper stays topped up and you never run dry.
- Overflow path: a lip near the hopper top drains excess back toward the trough, or a hopper-full
  switch cuts the auger. Either is fine; recirculation is simplest.

### Failure modes

- **Ball slips past the screw**: keep tube/screw clearance < ball radius; incline helps.
- **Double-entry jam**: a single-ball lip at the tube mouth meters the entry.
- **Joint step**: sand screw segment joints flush.

### Catch net

**Buy a table-tennis-robot catch net, do not build the funnel.** Robot nets already slope to a
single low collection channel — that solves "gather scattered balls to one point" for you. The
trough sits at that channel and feeds the auger mouth.

---

## 3. New hardware (everything else carries over)

| Item | Qty | For |
|---|---|---|
| Brushless motor matched to A2212 + 30 A ESC | 1 | 2nd launch wheel (you have one set) |
| Grippy launch wheels (~50–60 mm, rubber/foam or TPU+band) | 2 | launch |
| Continuous-rotation servo | 1 | escapement disk |
| 12 V DC gearmotor ~60 rpm + MOSFET/L298N driver | 1 | auger |
| 608 bearings | 2 | disk + auger shaft |
| 8 mm steel rod (~900 mm) | 1 | auger core |
| Table-tennis robot catch net | 1 | catch + funnel |

Aim servos (MG996R ×3: pan, tilt, head-roll), PCA9685 HAT, Pi, LiPo all reused.
**De-risk order: print and bench-test the escapement and the auger as standalone subassemblies
before committing to a frame.** They're the only novel mechanisms; launch wheels are solved.

---

## 4. Control software

Yes, it needs code — but far less than the rally controller, and most drivers carry over. No
real-time vision loop, no strike-plane timing. It's a periodic scheduler + actuator drivers +
a drill library. New/changed packages (same `src/mcenroebot/<name>/` Protocol+Mock pattern):

| Package | State | Role |
|---|---|---|
| `drivers/bldc/` | reuse | throttle the 2 launch wheels via PCA9685 (extends `esc_arm`) |
| `drivers/servo/` | reuse | pan / tilt / head-roll |
| `drivers/feeder/` | new, tiny | escapement: `set_rate()` (v1) or `fire()` (+ index upgrade) |
| `drivers/lift/` | new, tiny | auger motor on/off/PWM, optional hopper-full switch |
| `launch/` | new | pure-math controller: `(speed, topspin, sidespin) → (top_rpm, bottom_rpm, head_roll°)`. Stateless + frozen value objects, mirrors `AimController`; target ≥95% coverage |
| `aim/` | reuse | existing yaw/pitch from a target point = "aim at this court location" |
| `drill/` | new | behavior engine: emits `Shot(speed, spin, target, interval)`; fixed patterns (oscillate / random / figure-8) **plus a pluggable `AimStrategy` Protocol** |
| `coordinator/` | simplify | periodic scheduler ticking the drill → launch + aim + feeder. Not a real-time loop |

Shelved (return-rally only): `trajectory`, `predictor`, `swing`.

---

## 5. Vision placement (the camera's role here)

Two different vision jobs — don't conflate them:

- **Rally-return prediction** (hard, shelved): see the incoming ball in 3D, predict the
  strike-plane crossing in < 100 ms. This is what drove the global-shutter stereo purchase. The
  feeder does not need it.
- **Placement aiming** (easy, and what you're now describing): look at the player / open court,
  decide where to send the *next* fed ball. Forgiving — you have the whole feed interval (1–2 s)
  to grab a frame, find the player, pick a target, and move the aim servos before the next ball
  reaches the wheels. **A single camera + simple player/zone detection is enough. No stereo, no
  3D ball tracking, no sub-100 ms timing.**

Architecturally this is just a `VisionPlacementStrategy` swapped in for `FixedPatternStrategy`
behind the `drill.AimStrategy` Protocol — zero change to the mechanism or the launch math. So:
v1 ships sensorless with fixed patterns; vision placement drops in later as a clean increment.

This does put an *easy* slice of vision back in the control path (last session it was "fully out").
That's fine — it's the slow, forgiving slice, not the hard rally slice.

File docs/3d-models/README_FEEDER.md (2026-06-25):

# Feeder (V4) 3D parts

Parametric parts for the spin/aim ball machine (see `../V4_PLAN.md`). Generated by
`generate_feeder_parts.py` — the same trimesh idiom as `generate_parts.py`. All parts are
watertight manifolds. Units mm.

## Regenerate

```bash
python3 generate_feeder_parts.py
```

Writes `F1_escapement_disk.stl` … `F5_launch_wheel.stl` into this folder. No new deps beyond
what `generate_parts.py` already uses (numpy + trimesh + a boolean backend). Edit the constants
block at the top to retune any dimension.

## Parts

| File | Bbox (mm) | Material | Print notes |
|---|---|---|---|
| `F1_escapement_disk` | 90 × 90 × 26 | PETG | Flat, pocket-up. Smooth bed face down (it's the rubbing face) or sand it. |
| `F2_hopper_cone` | 206 × 206 × 153 | PLA/PETG | Outlet-down, no supports (62° walls self-support). 200 mm footprint — near bed edge; section if needed. |
| `F3_auger_screw` | 44 × 44 × 113 | PETG | Print upright with supports on the flight undersides, **or** at ~45° to reduce overhang. 2 turns/segment. |
| `F4_auger_tube` | 59 × 59 × 112 | PETG | Upright, socket-up. Vase/thin-wall settings fine; needs to be straight. |
| `F5_launch_wheel` | 55 × 55 × 18 | PETG/TPU | Flat. Print 2. TPU tread or seat a rubber band/O-ring in the groove. |

## Assembly notes / things the blanks don't encode

- **Escapement housing (not generated).** `F1` is the indexing disk only. It needs a housing/
  baseplate that places the hopper **load port** and the **discharge port** both at radius
  `POCKET_CENTER_R` (22 mm), at different angles, with the disk's solid face sealing both between
  index steps. `F2`'s 50 mm outlet funnels into the load port — it is **not** meant to dump on the
  disk axis. Design the housing once the disk + servo coupling is in hand.
- **Disk drive.** Four M3 holes on a 16 mm BC (underside) bolt to a continuous-rotation servo horn;
  the 608 counterbore + 8 mm pivot bore take the radial load off the servo shaft.
- **Auger stacking.** `F3` is 2 full turns, so flights align when segments are threaded onto the
  8 mm rod — keep them rotationally indexed and the flight is continuous. Grub screw per segment.
- **Auger inlet.** The **bottom** tube section needs a side window cut for ball entry from the
  trough — not in the generic `F4`. Add a `~50 × 40 mm` slot near its base (or set a flag in the
  generator) for the inlet section.
- **Launch wheel bore.** `WHEEL_BORE` defaults to 5 mm — **measure your A2212 collet adapter and
  retune** before printing. Grub screw locks to the shaft/collet flat.

## Validation (as generated)

All five export watertight (`is_watertight = True`, `is_volume = True`). Face counts 1.3k–2.4k;
files are small. Re-running the generator reproduces them exactly.

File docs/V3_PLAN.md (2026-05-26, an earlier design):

# McEnroe V3 — Defensive-Competitive Ping Pong Robot

Builds on [`V2_PLAN.md`](V2_PLAN.md). V2 was aim-and-swat: can make contact with a ball passing through a fixed strike plane, swing is open-loop, returns are uncontrolled. V3 is a **defensive competitive opponent** — robot that reliably returns most balls within reach with controlled trajectory (no lobs), can chase the ball along its end of the table, and runs a learned policy for the swing decision.

Read V2_PLAN.md first for the design rationale and existing module specifications; this document is the V3 build plan.

---

## 0. Context

**Goal:** A robot that plays defensive competitive ping pong. The robot's job is to *return* the ball — not to win points by attacking. It loses points when AJ hits placements it mechanically can't reach (drop shots, lobs, sharp angles), not when AJ hits it cleanly past. Think "wall that gives the ball back," Murray to AJ's Federer.

**Non-goals for V3:**
- Spin generation (paddle face is controllable mid-stroke via wrist servo, but no advanced spin shots)
- Smashing / offensive shot selection
- Multi-stroke variety (forehand vs backhand vs lob defense)
- Beating AJ at AJ's best — explicitly out of scope (see §9)

**Budget envelope:** $500–$1,500 incremental over V2. Targeting ~$500–$700 for the core build.

**Working directory:** `/Users/alberthurwitz/Projects/mcenroebot` (same as V2). Branching plan in §7.

---

## 1. Target performance

Quantitative targets the final V3 should hit, measured against AJ's normal recreational play (not AJ's full effort):

| Metric | Target | Notes |
|---|---|---|
| Return success rate (ball within reach) | 80–90% | "Within reach" = anywhere along the linear axis, within turret aim envelope |
| Return trajectory | Flat or slight topspin | Net clearance 5–15 cm above the net, lands on AJ's side within 30 cm of the far edge typically |
| Rally length | 8–20+ shots | Long enough that AJ has to actively try to win points |
| Latency (camera → motor command) | <100 ms | Includes prediction, policy inference, motor command issuance |
| Reach (along table edge) | ~1.5 m | Full width of one table-end |
| Reach (depth from net) | Fixed strike plane | No depth chase — accept this limitation |
| Point share against AJ's normal play | 25–40% to robot | Robot defends, AJ attacks |
| Point share against AJ's full effort | 5–15% to robot | Honest expectation — see §9 |

---

## 2. Architecture overview

V3 = V2 turret + closed-loop swing + linear axis + wrist + RL policy.

```
                      [ AJ ]
                        │
              ╔═════════╧═════════╗
              ║   PING PONG TABLE  ║
              ╠═══════════════════ ╣
                        │
                 [ robot side ]
   ◄───────────── 1.5 m linear rail ─────────────►
              │           │            │
              │    [ V2 turret    ]    │   ← rides on carriage
              │    [   on cart    ]    │
              │           │            │
              │           ▼            │
              │      ┌────────┐        │
              │      │ closed │        │
              │      │ loop   │        │  ← gimbal BLDC + AS5600 encoder
              │      │ swing  │        │
              │      └───┬────┘        │
              │          │             │
              │      [ wrist servo ]   │  ← small servo for paddle-face angle
              │          │             │
              │      [ paddle ]        │
```

Major changes vs V2:

1. The whole V2 turret (base plate, yaw bracket, pitch bracket, swing arm, paddle clamp) is mounted on a **moving carriage** on a 1.5 m linear axis at the back edge of the table.
2. The A2212 BLDC + ESC is replaced by a **brushless gimbal motor + AS5600 magnetic encoder + SimpleFOC controller** on an STM32 microcontroller. Closed-loop position control of the paddle.
3. A small **wrist servo (MG90)** between the swing arm and the paddle clamp lets the paddle face tilt independently of the swing arm angle.
4. The control loop runs a **learned policy** (PPO trained in PyBullet sim) instead of the open-loop `SwingProfile`.

---

## 3. Hardware additions and BOM

| Item | Purpose | Est. cost (USD) |
|---|---|---|
| **Closed-loop swing module** | | |
| BGM4108-130 (or equiv) brushless gimbal motor | J3 swing, replaces A2212 | $40 |
| AS5600 magnetic encoder breakout + diametric magnet | Paddle angular position feedback | $10 |
| STM32 "Blue Pill" or Bluepill+ (F103) | SimpleFOC controller runtime | $15 |
| Dual L6234 / DRV8313 driver board | 3-phase motor driver for gimbal motor | $15 |
| 12V 3A bench PSU (or repurpose existing) | Gimbal motor power | $20 |
| **Wrist axis** | | |
| MG90S micro servo | Paddle-face angle (±45° range) | $5 |
| 3D-printed wrist bracket (`06_wrist_yoke.stl`) | Couples swing arm to paddle clamp via servo | $0 (print) |
| **Linear axis** | | |
| NEMA 17 stepper motor (1.8°, ~45 N·cm) | Carriage drive | $20 |
| TMC2209 stepper driver (silent, microstepping) | Motor driver | $10 |
| 1.5 m V-slot 2040 aluminum extrusion | Carriage rail base | $50 |
| 2× 1.5 m MGN12 linear rails + carriages | Precision motion | $80 |
| GT2 belt (3 m) + 20T pulley + tensioner | Belt drive | $20 |
| End caps, motor mount, idler pulley bracket | Mechanical assembly | $30 |
| Limit switches (2, end-of-travel) | Homing / safety | $5 |
| Raspberry Pi GPIO → step/dir pulse generator (or use PCA9685 spare) | Step pulse source | $0 (reuse) |
| **Carriage adaptor** | | |
| 3D-printed carriage plate (`07_carriage_plate.stl`) | Bolts MGN12 carriages to V2's `01_base_plate.stl` | $0 (print) |
| **Misc** | | |
| Drag chain for cables | Cable management as carriage moves | $15 |
| Extra 5V/3A PSU | Wrist servo + logic power | $15 |
| Hardware (M3/M4 screws, T-nuts, brackets) | Fastening | $20 |

**Subtotal:** ~$370–$430 for parts + ~$50 contingency = **$450 target**, $600 worst case.

**Reused from V2 (nothing new bought):**
Raspberry Pi 4, PCA9685 HAT, MG996R servos (J1 yaw, J2 pitch — kept), Logitech webcam, 3S LiPo + B6 charger, 608ZZ bearings, F-clamps, plywood base, hardware kits, V2 3D-printed brackets (01–05).

**Deliberately skipped for V3 (deferred to V4):**
- Faster aiming servos (DS3225 etc.) — MG996Rs are *just* fast enough at recreational pace
- Higher-fps camera (Pi Global Shutter, Arducam B0392) — defensive play tolerates 30 fps OK
- Z-axis (vertical reach) — accepts loss to lobs and drop shots
- Multi-camera / stereo — monocular depth from ball radius is adequate for V3

---

## 4. Software architecture

V3 adds three new packages and modifies two existing ones. Layout under `src/mcenroebot/`:

```
mcenroebot/
├── aim/            (V2, unchanged)
├── ball/           (V2, unchanged)
├── camera/         (V2, unchanged)
├── clock/          (V2, unchanged)
├── predictor/      (V2, unchanged)
├── calibrate/      (V2, unchanged)
├── drivers/
│   ├── servo/      (V2, unchanged — still drives J1, J2, and new wrist)
│   ├── bldc/       (DEPRECATED — replaced by foc/ in V3; kept on develop until V4 migration)
│   ├── foc/        (NEW — SimpleFOC-over-serial driver for closed-loop swing motor)
│   └── stepper/    (NEW — TMC2209-over-step/dir driver for the linear axis)
├── swing/          (REPLACED — was open-loop SwingProfile; now wraps the closed-loop FOC driver)
├── linear/         (NEW — carriage controller, homing, position planner)
├── wrist/          (NEW — paddle-face servo controller)
├── policy/         (NEW — three-layer policy stack; see §5)
├── sim/            (NEW — PyBullet world + episode runner + training infrastructure; dev-machine only)
└── coordinator/    (MODIFIED — now wires predictor → policy → {aim, linear, swing, wrist})
```

Each package follows V2's convention: directory with `__init__.py`, split files (protocol.py, real impl, mock impl, value objects, `__main__.py` for demo), tests under `tests/test_<name>/`.

### 4.1 `drivers/foc/`

Closed-loop swing motor driver. SimpleFOC runs on the STM32, exposes a serial protocol; the Pi talks to it via USB-serial.

```python
class FocDriver(Protocol):
    def home(self) -> None: ...                          # set current position as zero
    def move_to(self, angle_rad: float) -> None: ...     # blocking move with PID
    def velocity(self, omega_rad_s: float) -> None: ...  # constant velocity command
    def stop(self) -> None: ...
    @property
    def position_rad(self) -> float: ...                 # latest reported position
    @property
    def velocity_rad_s(self) -> float: ...

class SerialFocDriver:
    def __init__(self, port: str = "/dev/ttyACM0", baud: int = 115200): ...

class MockFocDriver:
    """Records all commands for tests; simulates the position trajectory."""
```

### 4.2 `drivers/stepper/`

```python
class StepperDriver(Protocol):
    def home(self) -> None: ...                          # rapid until limit switch
    def move_to_m(self, x_m: float) -> None: ...         # blocking position move
    def set_velocity(self, v_mps: float) -> None: ...    # constant velocity
    @property
    def position_m(self) -> float: ...

class TMC2209StepperDriver:
    """GPIO step/dir pulse generator, optionally with UART feedback for current limit."""
    def __init__(self, step_pin: int, dir_pin: int, enable_pin: int, steps_per_m: float): ...

class MockStepperDriver: ...
```

### 4.3 `swing/`

Replaces V2's `SwingProfile` + open-loop `SwingController`. New API:

```python
class SwingCommand(BaseModel):
    model_config = ConfigDict(frozen=True)
    target_angle_rad: float    # paddle angle at strike (in swing arm frame)
    target_velocity_rad_s: float  # angular velocity at strike
    fire_time: float           # absolute time to start the swing
    wrist_angle_rad: float     # paddle face angle relative to swing arm

class SwingController:
    """Closed-loop swing. Pre-positions paddle, then accelerates to target
    velocity at fire_time, hitting target_angle with target_velocity at T0."""
    def __init__(self, driver: FocDriver, wrist: WristController, clock: Clock): ...
    async def execute(self, cmd: SwingCommand) -> None: ...
```

### 4.4 `linear/`

```python
class LinearCarriage:
    """1-DOF cart along table edge. Position 0 = home (left limit)."""
    def __init__(self, driver: StepperDriver, max_velocity_mps: float = 1.0): ...
    async def go_to(self, x_m: float) -> None: ...
    async def home(self) -> None: ...
    @property
    def position_m(self) -> float: ...
```

### 4.5 `wrist/`

Thin wrapper around `ServoDriver` for the MG90 on a dedicated PCA9685 channel.

### 4.6 `policy/`

Three implementations behind a single Protocol — the key V3 abstraction. See §5.

### 4.7 `sim/`

Dev-machine only — not deployed to Pi. PyBullet world with:

- Ball: point mass + drag + (optional) Magnus force
- Table: plane primitive with COR
- Paddle: flat plate primitive with COR
- Robot: kinematic model matching real geometry (V2 turret on linear carriage)
- Opponent: scripted ball server that varies launch position, velocity, spin

```python
class PingPongSim:
    def reset(self) -> Observation: ...
    def step(self, action: SwingCommand) -> tuple[Observation, float, bool, dict]: ...
    # Standard Gymnasium-compatible env interface
```

### 4.8 `coordinator/`

Modified `RallyCoordinator`:

```python
class RallyCoordinator:
    def __init__(
        self,
        aim: AimController,
        predictor: TrajectoryPredictor,
        policy: Policy,                       # NEW
        carriage: LinearCarriage,             # NEW
        servo_driver: ServoDriver,
        swing: SwingController,
        wrist: WristController,               # NEW
        clock: Clock,
        ...
    ): ...
    async def step(self, obs: BallObservation) -> None:
        """1. push observation to predictor
           2. if prediction available: ask policy for SwingCommand
           3. dispatch carriage move, turret aim, wrist preset
           4. fire swing at SwingCommand.fire_time"""
```

---

## 5. The three-layer policy stack

V3's centerpiece. Each layer is a drop-in replacement for the previous, sharing a Policy Protocol:

```python
class Policy(Protocol):
    def act(
        self,
        prediction: StrikePrediction,
        robot_state: RobotState,
    ) -> SwingCommand | None: ...
```

### 5.1 `HeuristicPolicy` (Phase A)

Hand-tuned rules. **Ships first** so we have a working baseline before any learning. Examples:

- If ball arrives <0.8 m/s, set wrist to +5° (slight upward); else 0°
- Always strike at `paddle_angle_at_strike = π/2` (paddle horizontal, moving forward)
- Always strike at `paddle_velocity = 4 rad/s` (medium swing)
- Always target the center of opponent's side

Maybe 100 lines of code. Plays "competently dumb" — returns balls, slightly inefficient.

### 5.2 `AnalyticalPolicy` (Phase B)

Closed-form trajectory optimization. Given the predicted ball state and a desired landing point (e.g. far baseline center), solve for paddle face angle and velocity that produces a ball trajectory landing there. Uses the same ballistic + Magnus model the predictor uses (inverted).

This is the **strong baseline** for the RL policy to beat. In practice, an analytical policy often gets 80%+ of the RL ceiling on this kind of low-dim control problem.

### 5.3 `LearnedPolicy` (Phase C — the RL piece)

PPO-trained neural network. Architecture:

- Observation (~20 dims): predicted strike state (x, y, z, vx, vy, vz, time-to-impact, confidence), robot state (carriage position, J1, J2 angles, paddle angle, wrist angle, ready/busy flag), opponent indicator features (recent ball variance)
- Action (~5–6 dims, continuous, bounded): target paddle angle, target paddle velocity, wrist angle, carriage target offset, fire time delta
- Reward: +1 ball returned over net + on opponent's side; -1 missed/out; +shaping for low-arc trajectory + small action-magnitude penalty

Training:

- **Sim:** PyBullet world from §4.7
- **Algorithm:** PPO via stable-baselines3 (well-tested), 1–2M steps, runs overnight on a laptop GPU
- **Domain randomization:** ball mass (2.5–2.8 g), drag (±20%), paddle COR (0.80–0.92), servo latency (10–80 ms), motor torque (±20%), camera observation noise (Gaussian σ varied), table COR
- **Curriculum:** start with slow balls and narrow placement variance; ramp up speed/variance over training
- **Sim-to-real transfer:** deploy policy, log real-world rallies, retrain with parameters tuned to observed system. Two or three iterations of this typically closes the gap.

The learned policy gets loaded from a checkpoint at runtime; inference is a single PyTorch forward pass (~1 ms on Pi 4 CPU).

### 5.4 Why layer them

- **Baseline guarantee.** If the RL pipeline takes longer than expected (it will), V3 still ships with the analytical policy working. The hardware payoff doesn't depend on the RL payoff.
- **A/B comparison.** You get a real measurement of how much the RL adds over hand math. That's the interesting research finding even if both work.
- **Debugging.** When the RL policy misbehaves on real hardware, you can swap back to analytical to isolate "is this an RL problem or a hardware/sim problem?"

---

## 6. Build phases (waves)

### Wave 0 — V2 baseline lockdown (this week, prereq)

Open the PR `feature/v2-control` → `develop` from current state. Run hardware once on the Pi to confirm V2 actually works end-to-end. Camera-calibrated. We need a **working V2** before we start replacing parts.

### Wave 1 — Closed-loop swing module (~2 weeks, $80–150 hardware)

1. New packages `drivers/foc/` + modified `swing/` with mock-driver tests.
2. Flash SimpleFOC onto STM32 with a serial command protocol.
3. Bench-test the gimbal motor + encoder closed-loop without paddle.
4. Mechanical: 3D-print a mount that replaces the A2212 in the V2 `03_pitch_bracket.stl` (parametric — regenerate via `generate_parts.py` with new constants).
5. Mount paddle, characterize step-response and bandwidth.
6. **Phase gate:** can the closed-loop swing land at a commanded `(angle, velocity)` within ±5° and ±0.5 rad/s of target on a stationary turret? If yes, proceed.

### Wave 2 — Wrist axis (~1 week, $5 hardware)

1. New package `wrist/` with mock-driver tests.
2. Mechanical: print `06_wrist_yoke.stl` — couples swing arm tip to paddle clamp via the MG90 servo.
3. Bench-test wrist range and accuracy.
4. **Phase gate:** can the wrist hold an arbitrary face angle in the range [−45°, +45°] within ±2°?

### Wave 3 — Linear axis (~3 weeks, $300–400 hardware)

This is the biggest mechanical build.

1. New packages `drivers/stepper/` + `linear/` with mock-driver tests.
2. Mechanical: V-slot extrusion bed, MGN12 rails, GT2 belt, NEMA17 + TMC2209 wiring.
3. 3D-print `07_carriage_plate.stl` to adapt MGN12 carriages to V2's `01_base_plate.stl`.
4. Limit-switch wiring + homing routine.
5. Calibrate steps-per-meter empirically.
6. **Phase gate:** can the carriage move to a commanded position in [0, 1.5] m within ±2 mm in <1 s?

### Wave 4 — Coordinator integration with `HeuristicPolicy` (~1 week, no hardware)

1. New package `policy/` with `HeuristicPolicy` only.
2. Modify `coordinator/` to wire all V3 axes together.
3. Integration tests with mock everything.
4. **Phase gate:** can the simulated rally coordinator return balls back over the net in 100/100 deterministic test cases?

### Wave 5 — First live rally (~1 week, no hardware)

1. SSH/deploy to Pi.
2. Wire all hardware: V2 turret on carriage, FOC over USB-serial, stepper via GPIO, wrist on PCA9685 spare channel.
3. Run rally with heuristic policy.
4. **Phase gate:** robot makes contact with >50% of balls AJ feeds at slow-medium recreational pace, returns at least 25% over the net. **Champagne moment.**

### Wave 6 — `AnalyticalPolicy` (~2 weeks, no hardware)

1. Closed-form trajectory inversion in `policy/analytical.py`.
2. A/B vs heuristic in offline tests + live rally.
3. **Phase gate:** analytical policy beats heuristic by ≥15% on return-success-rate over a 100-rally test.

### Wave 7 — `LearnedPolicy` (RL) (~4–8 weeks, no hardware initially)

1. Build `sim/` PyBullet world.
2. Implement PPO training loop with `stable-baselines3`.
3. Domain randomization config.
4. Train overnight; iterate on reward shaping.
5. Deploy checkpoint; collect real-world rally logs.
6. Sim-to-real iteration (2–3 cycles).
7. **Phase gate:** RL policy beats analytical by ≥10% on return success rate AND matches or beats it on average rally length.

### Wave 8 — Polish (~2 weeks)

Robust failure modes (lost predictions, overrun limit switches, paddle wedged at top of arc, etc.), audio cues / trash talk integration, README updates, demo video.

**Total V3 timeline:** roughly 4–6 months at evening pace. Hardware-build is the early gating factor; RL is the long-tail risk.

---

## 7. Branching strategy

```
develop (V2 complete)
   │
   ├── feature/v3-foc        — Wave 1
   ├── feature/v3-wrist      — Wave 2
   ├── feature/v3-linear     — Wave 3
   ├── feature/v3-policy     — Waves 4 + 6 (heuristic + analytical)
   ├── feature/v3-sim        — Wave 7 (sim + PPO training, dev-only)
   └── feature/v3-integrate  — Wave 5 + 8
```

Each merges into `develop` after its phase gate is green. V3 production-release tag once all eight waves land.

---

## 8. Sim-to-real strategy

The single largest risk on V3 is the sim-to-real gap. Mitigation:

1. **Build sim AFTER hardware exists, not before.** This is counter to most RL projects but crucial here. Real-world measurements (servo step response, motor latency, paddle COR, table COR, lighting/camera noise) feed directly into sim parameter ranges. Sim built in a vacuum is fiction.
2. **Domain randomization is non-negotiable.** Single-parameter sim policies overfit and break on contact with real-world variance.
3. **Validate sim against real rallies regularly.** Periodically run a "sim replay" of a logged real-world rally and compare predicted vs actual ball trajectory. If sim diverges, fix sim before training new policies.
4. **Keep the analytical policy as the safety net.** If RL goes off the rails after sim-to-real, fall back.

---

## 9. Open questions and honest limitations

### 9.1 What V3 will *not* do

- **Spin estimation from incoming ball.** Requires 60+ fps stereo or DVS camera. Deferred to V4.
- **Lob defense or drop-shot defense.** No Z-axis = no vertical reach. Deferred to V4.
- **Multiple shot types (smash, slice).** Defensive scope only.
- **Beating AJ at AJ's best.** That's V4+ territory: high-fps cameras, possibly a full multi-DOF arm, and offensive shot selection. V3 is the foundation for that, not the destination.

### 9.2 Risks specific to V3

- **Closed-loop swing tuning.** Gimbal motor + AS5600 + SimpleFOC is well-trodden territory (lots of community resources), but tuning the PID gains for a paddle-loaded arm with high-impulse strikes is non-trivial. Budget extra time on Wave 1.
- **Belt-driven linear axis precision under acceleration.** 1.5 m belt at high carriage acceleration can introduce position errors >5 mm if belt tension drifts. May need ballscrew or rack-and-pinion in V3.5 if precision turns out to be insufficient.
- **Mechanical latency stacking.** Camera (33 ms) + prediction (5 ms) + policy (1 ms) + serial comms (5 ms) + motor response (20 ms) + mechanical (15 ms) ≈ 80 ms total. Tight against the 100 ms target. Need to measure on real hardware and budget aggressively.
- **PPO + sim-to-real overrun.** This kind of project routinely overruns. Wave 7 is timeboxed at 4–8 weeks; if it goes past 12, ship V3 with the analytical policy and call the RL pass V3.5.

### 9.3 Things to revisit after Wave 5 (first live rally)

- Is MG996R aim speed adequate, or do we need DS3225 servos? (V3.5 add-on if needed.)
- Is 30 fps camera adequate, or do we need 60+ fps for prediction tightness? (V3.5 add-on if needed.)
- Does the gimbal motor have enough torque for paddle-load impact, or do we need a bigger one? (Could redesign Wave 1 hardware in V3.5.)

---

## 10. Success criteria for the whole of V3

V3 is "done" when:

1. The robot rallies with AJ for ≥10 consecutive shots in a row, more than once per session, at recreational pace.
2. AJ wins games against the robot by *placement* (drop shots, corners, lobs), not by *power* (clean drives).
3. The RL policy has been shown to beat the analytical baseline by a measurable margin (≥10% return success rate) on a fixed 100-rally test set, OR we've documented in the codebase exactly why it doesn't and what V4 would need to change.
4. The full test suite is green; coverage stays ≥85%; the README documents the deploy + calibrate + play workflow.

That's the goal. V4 is a separate document, written after V3 ships.

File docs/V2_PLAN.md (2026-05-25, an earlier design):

# McEnroe V2 — Turret Control Software Build Plan

Paste this entire file into a fresh Claude Code session in `/Users/alberthurwitz/Projects/mcenroebot`. It is self-contained.

---

## 0. Context

**Project:** McEnroe is a hobby ping-pong robot. V2 is the aim-and-swat phase: a 3-axis turret with two MG996R servos (J1 yaw, J2 pitch) for aiming, and an A2212 1000 KV brushless motor driven by an ESC (J3) for the open-loop paddle swing.

**Hardware:**
- Raspberry Pi 4 (Bookworm, Python 3.11) is the deploy target
- Adafruit-style 16-channel PCA9685 PWM HAT at I2C `0x40` — pan=ch0, tilt=ch1, BLDC ESC=ch2 (proposed)
- Single Logitech webcam at `/dev/video0` (2D — depth recovered from ball-radius monocular estimation)
- 3S LiPo for the BLDC; servos run off the HAT's screw terminal 5V/3A PSU

**Coordinate system (used everywhere):**
- Origin: J1 yaw axis at J2 pitch pivot height
- +X forward (toward the ball)
- +Y left (viewed from above)
- +Z up
- Units: meters internally, degrees for servo I/O, seconds for time

**Repo layout:**
- Working directory: `/Users/alberthurwitz/Projects/mcenroebot`
- Source: `src/mcenroebot/`
- Tests: `tests/`
- Python ≥3.10, pyproject already configured (ruff, mypy strict, pytest, ≥85% coverage floor, `pydantic.mypy` plugin)
- `uv` for deps — never edit `pyproject.toml` deps by hand, use `uv add`

## 1. Coding standards (mandatory)

- **OOP everywhere.** Public surface is classes. No bare module-level functions in the public API (private `_demo()` etc. are fine).
- **Pydantic v2** for every value object — `class Foo(BaseModel)` with `model_config = ConfigDict(frozen=True)`. Use `@field_validator` for range checks, not `__post_init__`. **Do not use `@dataclass`.**
- **Pydantic constructor calls are keyword-only** — write `Position3D(x=0.1, y=0.0, z=0.0)`, not `Position3D(0.1, 0.0, 0.0)`.
- **Type hints everywhere.** mypy strict must pass.
- **pytest** in `tests/test_<module>.py`. Cover happy paths and edge cases. Parametrize when useful. Use `pytest-asyncio` (already configured, `asyncio_mode = "auto"`) for async tests.
- **Coverage ≥85%** is enforced by `[tool.coverage.report] fail_under = 85`. Aim higher (≥95%) on pure-math modules.
- **Hardware abstraction:** every GPIO-touching driver has a `Protocol` interface and a `Mock<Name>Driver` implementation. The control loop is tested against mocks; the real drivers are only exercised on the Pi.
- **Pi-only deps go in an optional extra** so laptop dev/tests don't need them:
  ```toml
  [project.optional-dependencies]
  pi = [
      "adafruit-blinka",
      "adafruit-circuitpython-pca9685",
      "adafruit-circuitpython-servokit",
  ]
  ```
  Install on the Pi with `uv sync --extra pi`. In real drivers, do the Adafruit imports lazily inside `__init__` so importing the package on a Mac doesn't blow up.

## 2. Gitflow

- Branches: `main` / `develop` / `feature/*`
- Conventional commits (`feat:`, `fix:`, `refactor:`, `test:`, `chore:`, `docs:`)
- Current state: `feature/aim` is ahead of `develop` with the aim module
- Strategy (Option A — chosen): finish the aim pydantic refactor on `feature/aim`, merge to `develop` once, then cut `feature/v2-control` for the rest

## 3. Status as of handoff

**Already done on `feature/aim` (committed):**
- `src/mcenroebot/aim.py` — `AimController`, `Position3D`, `ServoAngles`, `TurretGeometry`
- `tests/test_aim.py` — 34 test cases
- `pyproject.toml` — strict mypy, ruff, pytest config, ≥85% coverage floor
- `pydantic >= 2.13.4` added as dep (commit `1a800bb`)

**Uncommitted on `feature/aim` (refactor in flight):**
- `src/mcenroebot/aim.py` — rewritten to use `pydantic.BaseModel` + `ConfigDict(frozen=True)` + `@field_validator`
- `tests/test_aim.py` — `Position3D(...)` call sites updated to keyword args; `pytest.raises(ValueError, ...)` for ServoAngles range check changed to `pytest.raises(ValidationError, ...)`; `pytest.raises(Exception)` mutation tests tightened to `pytest.raises(ValidationError)`

**What Claude Code needs to do FIRST (Wave 0):**
1. `uv sync` (refresh the venv if needed)
2. `uv run pytest -q` — all 34 tests should pass, coverage should stay above 85%
3. `uv run mypy src/` — should pass clean under strict
4. `uv run ruff check src/` — should pass clean
5. If any of (2–4) fail, fix before proceeding. Most likely surprise: pydantic v2 `ValidationInfo` import path or `field_validator` signature.
6. Commit: `git add -A && git commit -m "refactor(aim): migrate value objects to pydantic v2"`

## 4. Module specifications

All new modules live under `src/mcenroebot/`. Each has a matching `tests/test_<module>.py` with parametrized happy-path + edge-case coverage.

### 4.1 `clock.py`

Tiny module for testable timing.

```python
from typing import Protocol

class Clock(Protocol):
    def now(self) -> float: ...               # seconds since epoch (monotonic-ish)
    async def sleep(self, seconds: float) -> None: ...

class SystemClock:
    """Real wall-clock + asyncio.sleep."""

class FakeClock:
    """Deterministic clock for tests.
    - now() returns the internal time
    - sleep(s) advances the internal time by s, does NOT actually sleep
    - exposes .advance(seconds) and .elapsed for assertions
    """
```

Tests: monotonicity, sleep advances FakeClock, SystemClock.sleep actually awaits (use a small timeout + measure).

### 4.2 `ball.py`

Value objects + the depth-estimation abstraction.

```python
from pydantic import BaseModel, ConfigDict, field_validator

class BallObservation(BaseModel):
    """One sample from the tracker, in robot frame."""
    model_config = ConfigDict(frozen=True)
    t: float           # seconds
    x: float
    y: float
    z: float

class BallState(BaseModel):
    """Estimated position + velocity at a given time."""
    model_config = ConfigDict(frozen=True)
    t: float
    position: Position3D     # reuse from aim.py
    velocity: Position3D     # m/s, same coordinate frame

class StrikePrediction(BaseModel):
    model_config = ConfigDict(frozen=True)
    impact_point: Position3D
    impact_time: float        # seconds (absolute, same clock as observations)
    confidence: float = Field(ge=0.0, le=1.0)
```

Then the depth-estimation protocol:

```python
class PixelObservation(BaseModel):
    model_config = ConfigDict(frozen=True)
    t: float
    u_px: float               # image x
    v_px: float               # image y
    radius_px: float          # apparent ball radius

class DepthEstimator(Protocol):
    def estimate(self, obs: PixelObservation) -> BallObservation: ...

class BallRadiusDepthEstimator:
    """Monocular depth from apparent ball size.
        depth = (real_radius * focal_length_px) / pixel_radius
    Requires camera intrinsics (see camera.py).
    """
    def __init__(self, intrinsics: CameraIntrinsics, ball_radius_m: float = 0.020): ...
    def estimate(self, obs: PixelObservation) -> BallObservation: ...

# Stubs for future implementations (raise NotImplementedError):
class StereoDepthEstimator: ...
class RealSenseDepthEstimator: ...
```

Tests: known-good geometry round-trips through `BallRadiusDepthEstimator`; frozen-ness of all models; confidence bounds enforced by validator; ValidationError on negative radius_px.

### 4.3 `camera.py`

```python
class CameraIntrinsics(BaseModel):
    """Pinhole camera model. Fill from cv2.calibrateCamera output."""
    model_config = ConfigDict(frozen=True)
    fx_px: float
    fy_px: float
    cx_px: float
    cy_px: float
    distortion: tuple[float, float, float, float, float] = (0.0,) * 5
    image_width: int
    image_height: int

    # Helper: pixel → normalized camera ray (for ground-plane intersection later).
    def pixel_to_ray(self, u: float, v: float) -> tuple[float, float, float]: ...
```

Tests: round-trip a known projection; default distortion is zero; ValidationError on negative focal length.

### 4.4 `drivers/servo.py`

```python
class ServoDriver(Protocol):
    def write_angle(self, channel: int, angle_deg: float) -> None: ...

class PCA9685ServoDriver:
    """Real driver. Lazily imports adafruit_servokit on first use.
    Maps angle [0, 180] → PWM duty per servo's pulse_width_min/max.
    """
    def __init__(self, i2c_address: int = 0x40, frequency_hz: int = 50): ...

class MockServoDriver:
    """Records every write for assertions in tests."""
    @property
    def history(self) -> list[tuple[int, float]]: ...
```

Tests: MockServoDriver records calls in order; PCA9685ServoDriver raises a clear error if Adafruit libs aren't installed (skip the import-success test unless on Pi, mark it `@pytest.mark.integration`).

### 4.5 `drivers/bldc.py`

```python
class BLDCDriver(Protocol):
    def arm(self) -> None: ...
    def set_throttle(self, throttle: float) -> None: ...   # 0.0 .. 1.0
    def disarm(self) -> None: ...

class PCA9685BLDCDriver:
    """1000–2000 µs ESC PWM. Throttle 0 → 1000 µs, 1 → 2000 µs."""
    def __init__(self, channel: int = 2, i2c_address: int = 0x40, frequency_hz: int = 50): ...

class MockBLDCDriver:
    @property
    def armed(self) -> bool: ...
    @property
    def throttle_history(self) -> list[float]: ...
```

Tests: throttle outside [0, 1] raises; set_throttle before arm() raises; disarm zeros throttle.

### 4.6 `predictor.py`

```python
class TrajectoryPredictor:
    """Maintains a rolling buffer of BallObservations and fits a 3D
    ballistic trajectory: constant velocity in X, Y; gravity (-g) in Z.

    fit() uses weighted least squares. Recent observations weighted higher
    via exponential decay (configurable half-life).

    predict_strike(strike_plane_x) returns the (y, z, t) where the ball
    crosses x = strike_plane_x, or None if the ball is moving away.
    """
    def __init__(self, buffer_size: int = 16, gravity_mps2: float = 9.81,
                 weight_halflife_s: float = 0.1, min_observations: int = 3): ...
    def add(self, obs: BallObservation) -> None: ...
    def current_state(self) -> BallState | None: ...
    def predict_strike(self, strike_plane_x: float) -> StrikePrediction | None: ...
```

Tests:
- Synthetic ballistic trajectory recovers correct state to within tolerance
- Fewer than `min_observations` returns None
- Ball moving away from strike plane returns None
- Confidence increases with observation count; decreases with residual error
- Weights work: noisy old + clean new observations bias toward new

### 4.7 `swing.py`

```python
class SwingProfile(BaseModel):
    """Open-loop throttle envelope for one swing."""
    model_config = ConfigDict(frozen=True)
    ramp_up_ms: float = Field(gt=0)
    hold_ms: float = Field(ge=0)
    ramp_down_ms: float = Field(gt=0)
    peak_throttle: float = Field(gt=0.0, le=1.0)

    @property
    def total_ms(self) -> float: ...

class SwingController:
    """Drives the BLDC through a SwingProfile open-loop. No encoder feedback.
    Safety: refuses to fire if not armed. Auto-zeros throttle on context exit.
    """
    def __init__(self, driver: BLDCDriver, clock: Clock): ...
    async def __aenter__(self) -> SwingController: ...
    async def __aexit__(self, *exc: object) -> None: ...
    def arm(self) -> None: ...
    async def fire(self, profile: SwingProfile) -> None: ...
```

Tests (use MockBLDCDriver + FakeClock):
- Fire without arming raises RuntimeError
- Throttle history matches profile shape within tolerance (sample at N points)
- Total elapsed time on FakeClock matches profile.total_ms
- Context manager disarms on exit even if fire() raises

### 4.8 `calibrate.py`

```python
class EscCalibrator:
    """One-shot ESC calibration routine.
       1. Power off ESC. set_throttle(1.0). Power on ESC. Wait for beeps.
       2. set_throttle(0.0). Wait for beeps.
       3. disarm().
    Console-driven prompts between steps.
    """
    def __init__(self, driver: BLDCDriver, clock: Clock,
                 prompt_fn: Callable[[str], None] = input): ...
    async def run(self) -> None: ...
```

Tests: with MockBLDCDriver, FakeClock, and a `prompt_fn` that records prompts, verify the throttle sequence is `[1.0, 0.0, disarm]` in the correct order with the prompts in between.

### 4.9 `coordinator.py`

```python
class RallyCoordinator:
    """Top-level control loop. Wires:
       observations source → TrajectoryPredictor → AimController → SwingController
    """
    def __init__(
        self,
        aim: AimController,
        predictor: TrajectoryPredictor,
        servo_driver: ServoDriver,
        swing: SwingController,
        clock: Clock,
        strike_plane_x: float = 0.0,
        swing_latency_s: float = 0.05,   # how early to fire the swing
        servo_yaw_channel: int = 0,
        servo_pitch_channel: int = 1,
    ): ...

    async def step(self, obs: BallObservation) -> None:
        """Push one observation, update aim, decide whether to fire."""

    async def run(self, observation_stream: AsyncIterator[BallObservation]) -> None:
        """Main async loop. Pulls observations, calls step()."""
```

Tests (mocks + FakeClock):
- Synthetic incoming ballistic stream → servos receive aim updates → swing fires once at predicted impact_time - swing_latency
- Unreachable target: aim returns None, no swing fires
- Out-of-buffer (fewer than min_observations): swing does not fire
- Strike happens exactly once per "pass" — not retriggered

## 5. Wave structure for subagents

### Wave 0 — verify + commit the pydantic refactor (single agent or solo)
- Run pytest / mypy / ruff
- Fix any breakage
- Commit `refactor(aim): migrate value objects to pydantic v2`

### Wave 1 — independent foundation modules (parallel, 2 agents)
- **Agent 1A:** `clock.py`, `ball.py`, `camera.py` + tests
- **Agent 1B:** `drivers/__init__.py`, `drivers/servo.py`, `drivers/bldc.py` + tests + the `[project.optional-dependencies] pi = [...]` extra

After Wave 1: merge `feature/aim` → `develop` (`git checkout develop && git merge --no-ff feature/aim`), cut `feature/v2-control` from `develop`.

### Wave 2 — modules that depend on Wave 1 (parallel, 3 agents)
- **Agent 2A:** `predictor.py` + tests (depends on `ball.py`)
- **Agent 2B:** `swing.py` + tests (depends on `drivers/bldc.py`, `clock.py`)
- **Agent 2C:** `calibrate.py` + tests (depends on `drivers/bldc.py`, `clock.py`)

### Wave 3 — integration (single agent)
- **Agent 3A:** `coordinator.py` + integration tests
- Final: `uv run pytest`, `uv run mypy src/`, `uv run ruff check src/` all green
- Open PR `feature/v2-control` → `develop`

## 6. Commit hygiene

Each module + its tests should be its own conventional-commit. Examples:
```
feat(ball): add BallObservation, BallState, StrikePrediction, DepthEstimator
feat(camera): add pinhole CameraIntrinsics model
feat(drivers): add ServoDriver + BLDCDriver protocols, real + mock impls
feat(predictor): add TrajectoryPredictor with weighted ballistic fit
feat(swing): add SwingController + SwingProfile open-loop control
feat(calibrate): add EscCalibrator one-shot routine
feat(coordinator): wire predictor → aim → swing in RallyCoordinator
test(predictor): cover ballistic recovery, confidence, weighting
```

## 7. Pi deployment (deferred — after Wave 3 lands)

When the test suite is fully green on the laptop:
1. SSH/SFTP code to the Pi (`~/mcenroebot/`)
2. On Pi: `uv sync --extra pi`
3. Wire up: PCA9685 HAT at I2C `0x40`, servos on ch0/ch1, ESC signal wire on ch2
4. Run `python -m mcenroebot.calibrate` once to arm the ESC
5. Run the coordinator with the live webcam feed

## 8. Things to flag back to AJ before building

- **Camera intrinsics are not yet known.** `BallRadiusDepthEstimator` will need a real `CameraIntrinsics` instance. We should add a `scripts/calibrate_camera.py` (OpenCV checkerboard) as part of Wave 1 or call it out as a separate task. For now, ship with a placeholder intrinsics object in the demo and document the calibration step.
- **Strike plane location** is `x = arm_length_m` by default (0.20 m forward). Confirm this matches the physical setup once the turret is mounted.
- **Swing latency** (`swing_latency_s = 0.05`) is a guess. The first hardware-in-loop tests should measure actual mechanical latency and update this.
- **Trash talk audio** is out of scope for this plan. It can be added as a small `audio.py` later — `RallyCoordinator` should expose a hook.

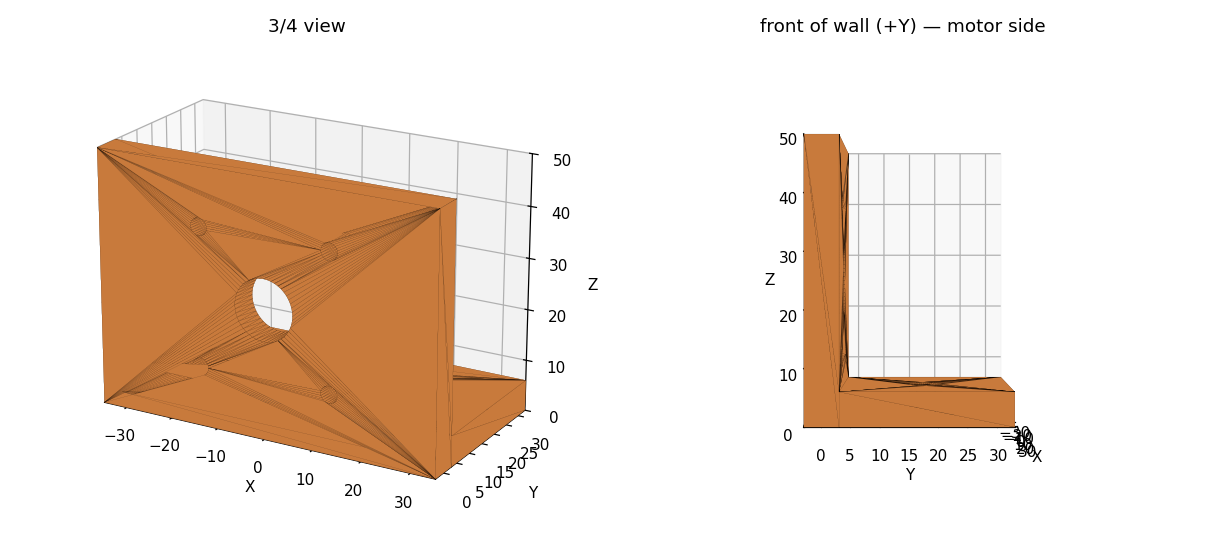
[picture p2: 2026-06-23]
docs/3d-models/03_pitch_bracket_FIXED.png

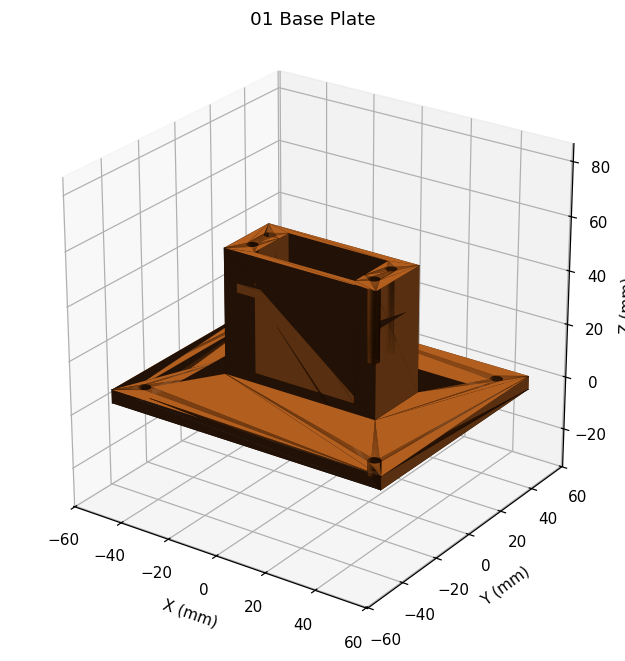
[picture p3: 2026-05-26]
docs/3d-models/01_base_plate.png

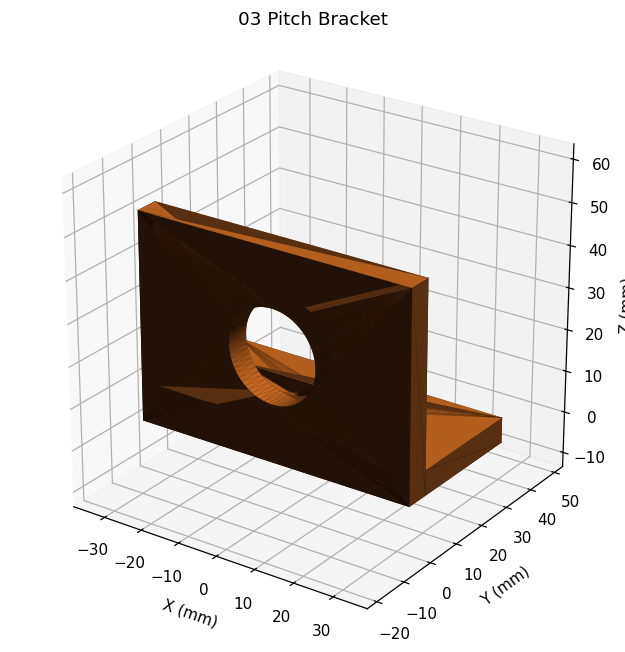
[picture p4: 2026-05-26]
docs/3d-models/03_pitch_bracket.png

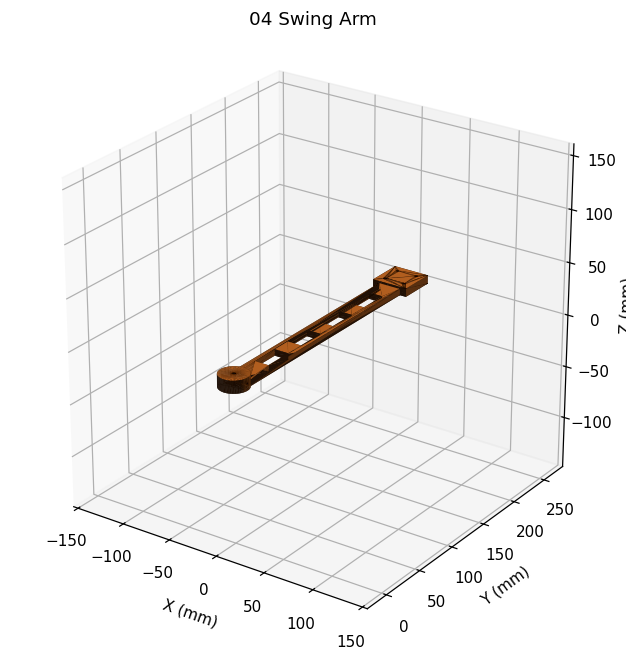
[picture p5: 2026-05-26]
docs/3d-models/04_swing_arm.png

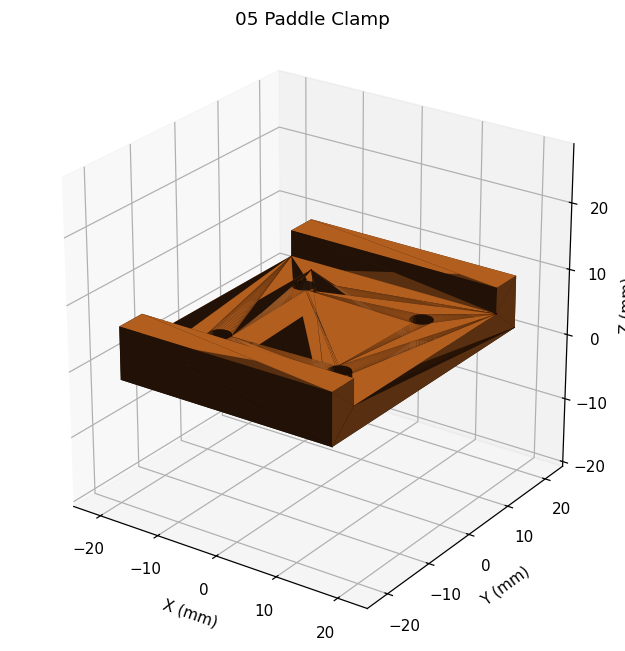
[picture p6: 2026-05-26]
docs/3d-models/05_paddle_clamp.png

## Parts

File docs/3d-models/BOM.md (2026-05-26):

# V2 Arm — Bill of Materials

Things you need on top of what you already have (Pi 4, P2S, filament, SG90s, etc.).

## Motors & motion

| Qty | Part | Why | ~Cost |
|---|---|---|---|
| 2 | MG996R metal-gear servo (180°) | J1 yaw + J2 pitch. SG90s won't hold the arm — the metal gears + 11kg-cm torque are the minimum here. | $14 (pair) |
| 1 | A2212 1000KV brushless outrunner | J3 swing motor. Already in the original BOM. | $10 |
| 1 | 30A ESC (e.g. Simonk / BLHeli) | Drives the A2212. Needs OneShot or PWM (Pi can do 50Hz servo PWM, good enough). | $8 |
| 1 | 3S 2200mAh LiPo + balance charger | Powers the BLDC. Don't try running this off the 5V wall wart. | $25 + $20 |
| 1 | XT60 pigtails + power switch | LiPo-to-ESC connection. | $5 |

The 5V/3A supply you have can stay on the Pi + servos circuit. Keep the LiPo
circuit isolated — common ground only.

## Bearings & shafts

| Qty | Part | Where it goes | ~Cost |
|---|---|---|---|
| 2 | 608ZZ skate bearing (8mm bore, 22mm OD) | One in the pitch bracket for swing-axis radial support, one as a yaw-axis thrust support (optional v1) | $4 (pack) |
| 1 | 5mm × 60mm steel rod (or M5 bolt + nuts) | Swing-axis stub shaft on the far side of the swing arm hub | $2 |

## Fasteners

| Qty | Part | Where |
|---|---|---|
| 16+ | M3 × 12mm socket head | General assembly |
| 8 | M3 × 20mm socket head | Paddle clamp through-bolts |
| 8 | M4 × 16mm socket head | Servo ears + base plate to base |
| 1 set | M3 / M4 nylock nuts | Paddle clamp, base plate |
| 4 | M3 × 6mm set screw | Hub-to-shaft on the BLDC (only need 1, the rest are spares) |
| Optional | M3 brass heat-set inserts (10-pack) | If you want stronger threads in PETG. Press in with a soldering iron. | $6 |

## Paddle

| Qty | Part | Notes |
|---|---|---|
| 1 | Cheap recreational ping pong paddle | You'll cut the handle off and clamp the blade. Don't use your nice paddle for this. ~$8 |

## Total new spend (rough)

~$110 if you already have the A2212 from the original BOM, ~$120 with it included. Most of the cost is the LiPo + charger.

## Notes

- **Heat-set inserts are optional but recommended** for the swing arm hub — the
  set-screw will see vibration loads and a bare plastic thread will strip.
- **Don't skip the LiPo balance charger.** Charging a LiPo on a generic wall
  wart is how garage fires start.
- **The 5mm stub shaft on the swing arm far side is a v1.1 upgrade.** First
  prints can run the swing arm cantilevered off the BLDC shaft alone — it's
  marginal but will work for low-rate testing.

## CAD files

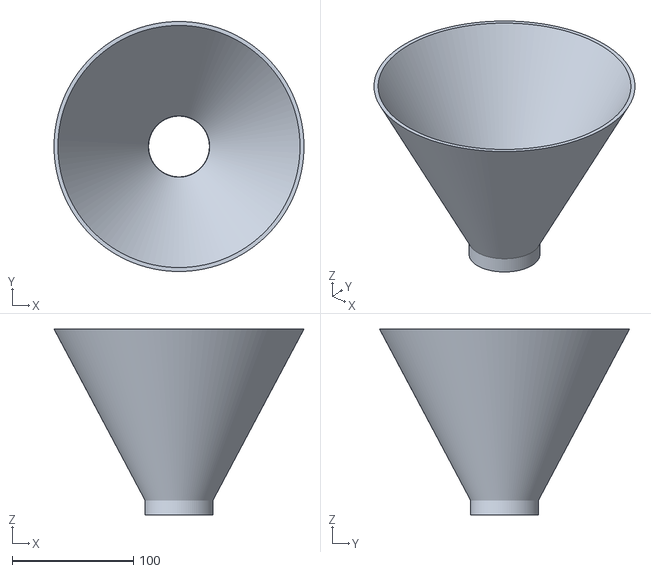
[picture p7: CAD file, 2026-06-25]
docs/3d-models/F2_hopper_cone.stl
206.0 x 206.0 x 153.1

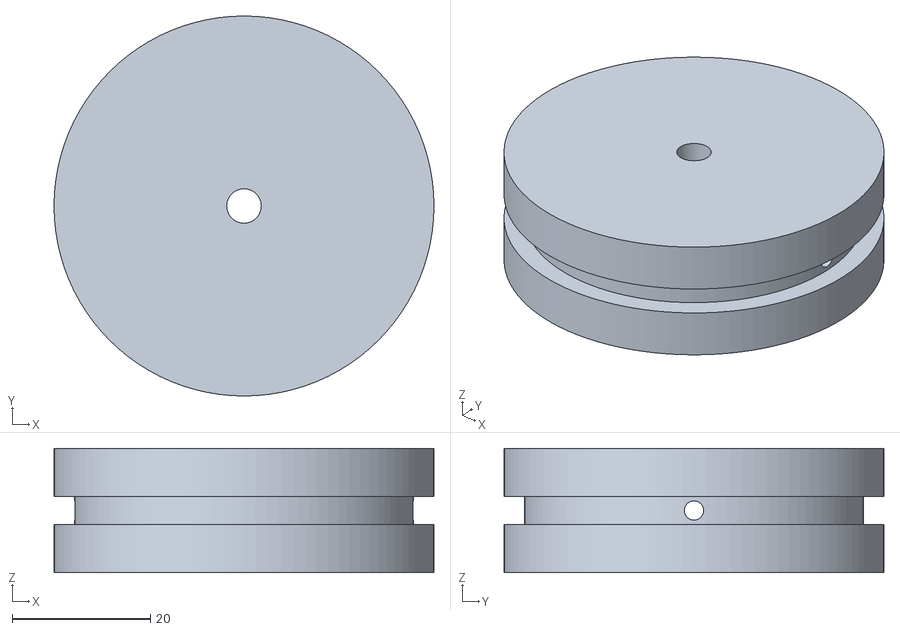
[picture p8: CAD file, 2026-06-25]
docs/3d-models/F5_launch_wheel.stl
55.0 x 55.0 x 18.0

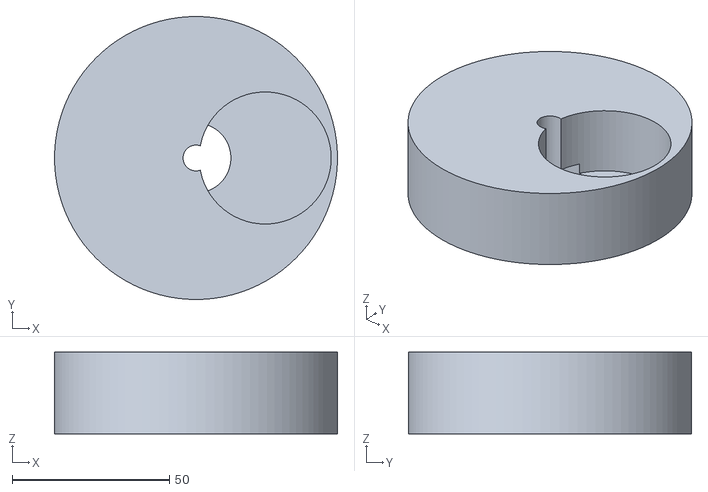
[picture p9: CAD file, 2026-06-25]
docs/3d-models/F1_escapement_disk.stl
90.0 x 90.0 x 26.0

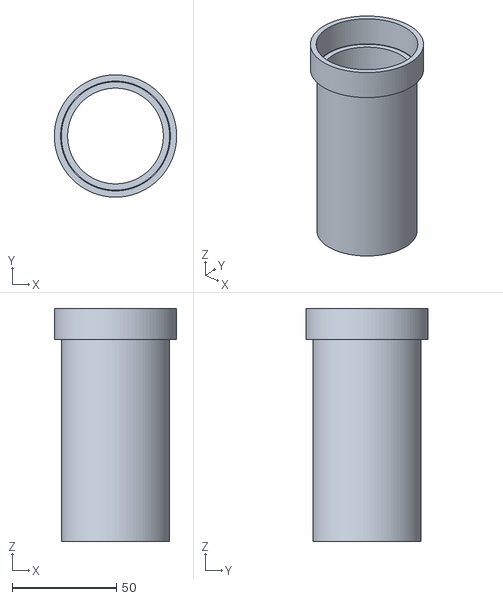
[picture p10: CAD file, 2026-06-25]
docs/3d-models/F4_auger_tube.stl
58.8 x 58.8 x 112.0

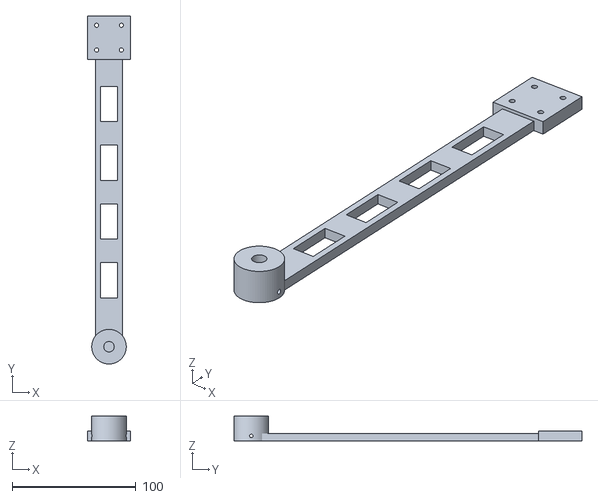
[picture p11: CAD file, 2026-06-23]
docs/3d-models/04_swing_arm_v2.stl
35.0 x 281.5 x 20.0

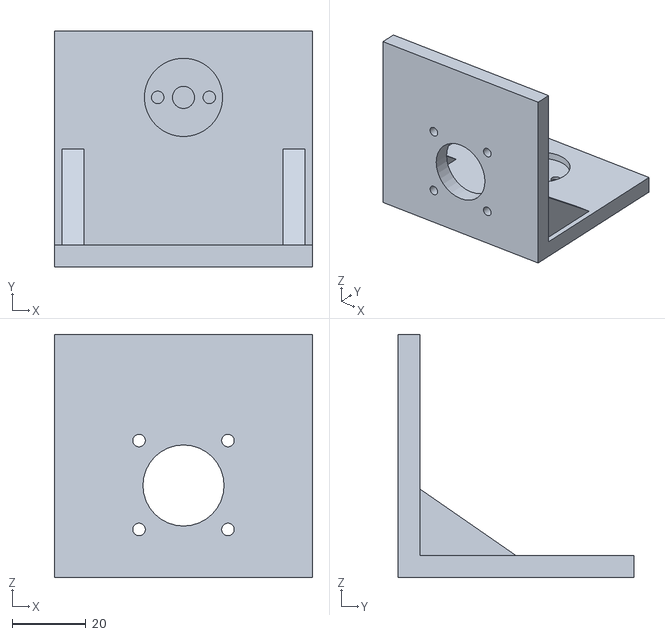
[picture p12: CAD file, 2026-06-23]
docs/3d-models/03_pitch_bracket_v3_FINAL.stl
70.0 x 64.0 x 66.0

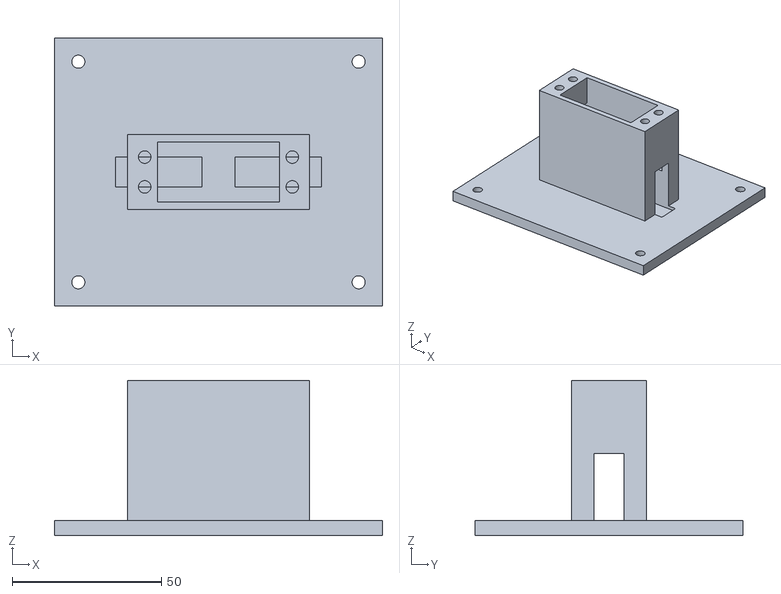
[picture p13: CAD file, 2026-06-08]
docs/3d-models/01_base_plate.stl
110.0 x 90.0 x 52.0

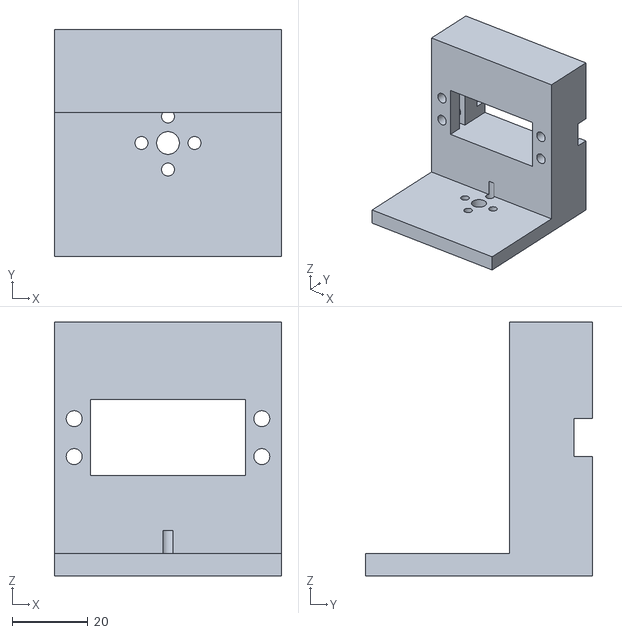
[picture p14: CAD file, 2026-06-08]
docs/3d-models/02_yaw_bracket.stl
60.0 x 60.0 x 67.0

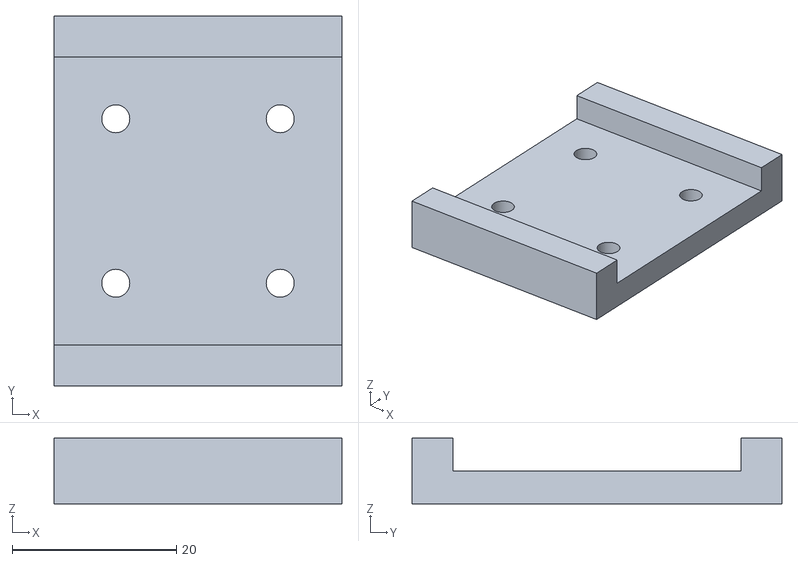
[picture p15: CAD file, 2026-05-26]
docs/3d-models/05_paddle_clamp.stl
35.0 x 45.0 x 8.00

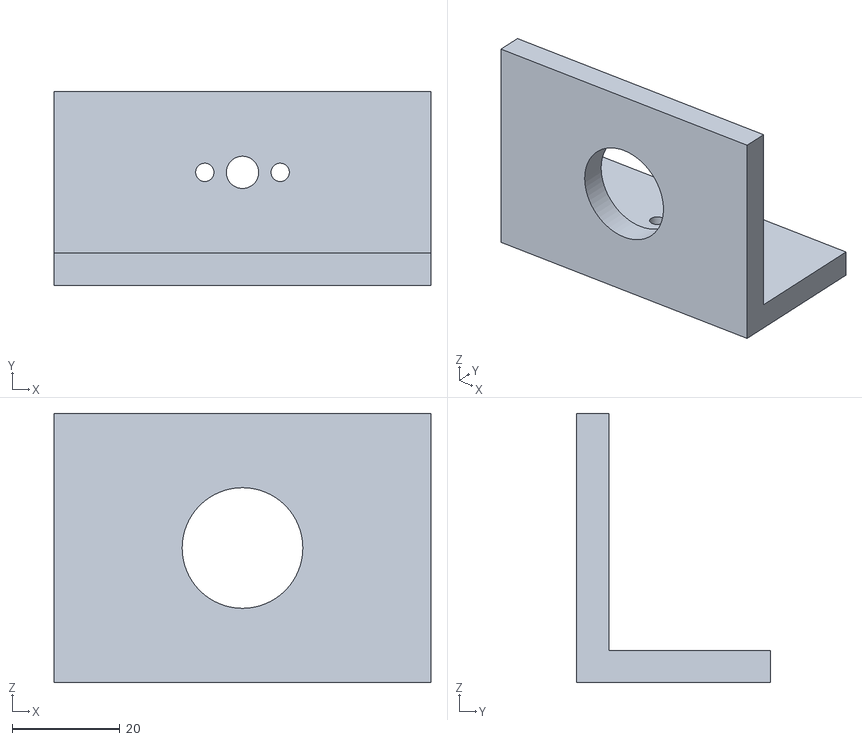
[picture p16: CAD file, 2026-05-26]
docs/3d-models/03_pitch_bracket.stl
70.0 x 36.0 x 50.0

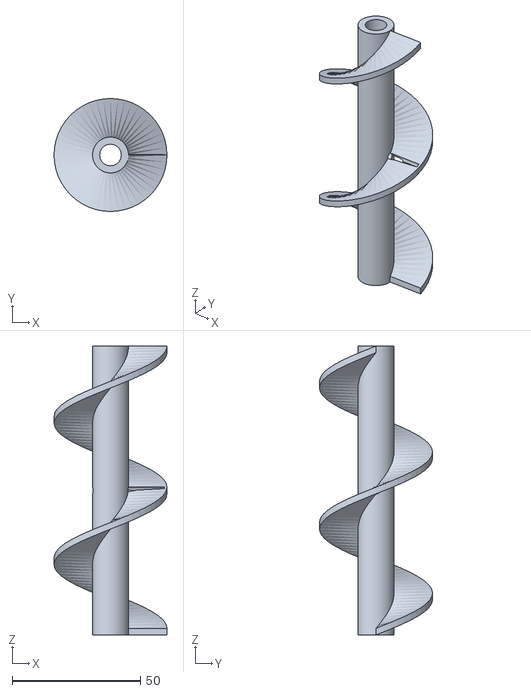
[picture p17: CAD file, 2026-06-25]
docs/3d-models/F3_auger_screw.stl
44.0 x 44.0 x 112.6

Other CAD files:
docs/3d-models/03_pitch_bracket_v3_motormount.stl
docs/3d-models/archive/03_pitch_bracket_v3_motormount.stl
docs/3d-models/04_swing_arm.stl
docs/3d-models/archive/04_swing_arm.stl

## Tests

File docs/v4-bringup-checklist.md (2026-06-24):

# V4 Feeder — Hardware Bring-Up Checklist

The software (Waves 0–6) is complete and verified off-Pi. This checklist is the **operator
runbook** for the two remaining phase gates, which require the Raspberry Pi and the assembled
machine. Work top-to-bottom; do not skip the de-risk steps.

Design source of truth: [`docs/superpowers/specs/2026-06-23-feeder-design.md`](superpowers/specs/2026-06-23-feeder-design.md).
Mechanism/BOM: [`docs/V4_PLAN.md`](V4_PLAN.md).

> **SAFETY (read first).** Launch wheels throw 40 mm balls hard — clear the room and wear eye
> protection. The escapement disk and auger pinch — keep fingers clear. Bench-test the escapement
> and auger as standalone subassemblies *before* committing to a frame (`V4_PLAN.md §3`).

---

## 0. Mechanical de-risk (before any software)

- [ ] Print + bench-test the **escapement** disk/hopper standalone — single-ball metering, no jam.
- [ ] Print + bench-test the **auger** standalone — balls ride up, no fallback, joints sanded flush.
- [ ] Mount the **catch net** (bought, not built) feeding the trough → auger mouth.

## 1. Pi setup

- [ ] `uv sync --extra pi` on the Pi (installs `adafruit-blinka`, `-pca9685`, `-servokit`, `RPi.GPIO`).
- [ ] Confirm I2C is enabled and the PCA9685 responds at `0x40` (`i2cdetect -y 1`).
- [ ] Reconcile the Python floor if needed (Pi is Bookworm 3.11; `pyproject.toml` already `>=3.11`).

## 2. Wiring + channel map

Confirm the channel assignment **and the shared-ground / power budget for two ESCs** before
powering on (spec §9). Planned map (also in `CLAUDE.md`):

| Ch | Actuator | Driver |
|---|---|---|
| 0 | pan servo (yaw) | `drivers/servo` |
| 1 | tilt servo (pitch) | `drivers/servo` |
| 2 | head-roll servo | `drivers/servo` |
| 3 | top wheel ESC | `drivers/bldc` |
| 4 | bottom wheel ESC | `drivers/bldc` |
| 5 | escapement CR servo | `drivers/feeder` |
| 6 | auger MOSFET PWM | `drivers/lift` |

- [ ] Hopper-full endstop (optional) on a BCM GPIO pin → `drivers/lift.GpioHopperSensor`.

## 3. Wave 5 — calibration + first live feed

- [ ] **Arm both ESCs**, once per wheel: `mcenroebot.calibrate.EscCalibrator` (or `scripts/esc_arm.py`).
- [ ] **Feeder factor:**
      `uv run scripts/calibrate_feeder.py --channel 5 --seconds 60`
      → paste `throttle_per_bpm` into `Pca9685FeederDriver(channel=5, throttle_per_bpm=…)`.
- [ ] **Launch constants** (measure no-load full-throttle rpm first, via tach/slow-mo):
      `uv run scripts/calibrate_launch.py --top-channel 3 --bottom-channel 4 --max-wheel-rpm <measured> --out launch_geometry.json`
      → load with `LaunchGeometry.model_validate_json(Path("launch_geometry.json").read_text())`.
- [ ] **First feed:** run `FeederCoordinator` with a `FixedPatternStrategy("static")` drill at low rpm,
      one fixed target. Wire the calibrated `LaunchGeometry` + `ThrottleMap` + the real drivers.

**Phase gate (Wave 5):** 20 consecutive balls to a chosen spot at controlled speed, no jam /
double-feed; auger keeps the hopper non-empty over a 5-minute run. 🍾

## 4. Wave 6 — vision placement (optional, after Wave 5 is solid)

- [ ] Mount the webcam (`/dev/video0`), confirm a frame source feeds `SimpleBlobDetector`.
- [ ] Tune `SimpleBlobDetector(half_width_m, threshold, min_area_frac)` against the real backdrop.
- [ ] Swap `VisionPlacementStrategy` in for the fixed pattern (inject detector + frame source +
      a fixed-pattern fallback). No other coordinator/launch changes are needed.

**Phase gate (Wave 6):** with the player standing left, ≥80% of balls land right of center (and
vice versa), at recreational pace.

## 5. Integrate

- [ ] After the Wave 5 gate passes, merge `feature/v4-feeder` → `develop`
      (the spec gates this merge on Wave 5; vision is a clean follow-up).

---

### Tuning notes carried from the spec (§9)

- ESC throttle→rpm is nonlinear under load; if launch speed is inconsistent, upgrade
  `calibrate_launch.py` to a 2nd-order / lookup curve instead of the linear `ThrottleMap`.
- If per-shot timing matters for vision sync, add the index endstop (`V4_PLAN.md §1`) and
  implement `FeederDriver.fire()` for a real `ball_fired` event (set `use_index_feeder=True`).

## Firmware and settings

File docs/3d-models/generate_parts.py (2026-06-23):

"""
McEnroe V2 arm — parametric STL generator.

Run: python3 generate_parts.py
Outputs: 01_base_plate.stl ... 05_paddle_clamp.stl  in this folder.

All units in millimeters. Edit the constants block to tweak dimensions.
"""

from __future__ import annotations

import os

import numpy as np
import trimesh
from trimesh.creation import box, cylinder

HERE = os.path.dirname(os.path.abspath(__file__))

# ---------------------------------------------------------------------------
# Constants — edit these to tune the design
# ---------------------------------------------------------------------------

# MG996R servo body (the aiming servos for yaw + pitch)
SERVO_W = 40.0  # length of body (measured: Deegoo MG996R)
SERVO_D = 19.0  # depth of body (measured)
SERVO_H = 43.0  # height of body, bottom to top of case below the hub (measured)
SERVO_EAR_THICK = 2.5
SERVO_EAR_EXTENT = 7.5  # how far ears stick out past the body on each side
SERVO_EAR_SCREW_D = 4.2  # M4 clearance for servo ear mounting screws
SERVO_EAR_SCREW_SPACING_X = 49.5  # center-to-center across the long axis
SERVO_EAR_SCREW_SPACING_Y = 10.0  # center-to-center across the short axis
SERVO_SHAFT_OFFSET_X = 9.8  # output shaft is offset from body center along X
SERVO_HORN_CLEAR_R = 12.0  # clearance hole radius for the round servo horn
SERVO_CLEAR = 0.5  # per-side print clearance so the servo actually slides into the pocket
SERVO_EXTRA_DEPTH = 2.0  # deepen the pocket so the body fully seats (motor was sticking out)

# A2212 brushless motor (the swing motor)
BLDC_OD = 28.0  # body outer diameter
BLDC_BODY_LEN = 30.0  # length of motor body
BLDC_SHAFT_D = 3.17  # 1/8" shaft (3.17mm)
BLDC_MOUNT_BOLT_CIRCLE = 19.0  # bolt circle diameter for the X-pattern mount
BLDC_MOUNT_SCREW_D = 3.4  # M3 clearance
# X-mount cross OUTER (tip) holes — what bolts the motor's mount cross to the
# bracket face. Measured tip-to-tip across the cross on the DYS D2826: 1.5 in = 38.1 mm.
BLDC_XMOUNT_BOLT_CIRCLE = 38.1
BLDC_WIRE_HOLE_D = 12.0  # center pass-through for the motor leads (base mounts flat)

# 608 skate bearings (yaw axis + swing axis side support)
BEARING_OD = 22.0
BEARING_ID = 8.0
BEARING_THICK = 7.0

# Hardware
M3_CLEAR = 3.4  # M3 clearance hole
M3_TAP = 2.8  # tapping into plastic (heat-set insert if you have them)
M4_CLEAR = 4.4
WALL = 3.0  # default wall thickness — generous because PETG and load
PLATE_T = 5.0  # default plate thickness

# Arm geometry
SWING_ARM_LEN = 250.0  # distance from BLDC shaft to paddle center
SWING_ARM_W = 22.0  # arm width
SWING_ARM_T = 6.0  # arm thickness
PADDLE_BLADE_W = 158.0  # standard paddle blade width
PADDLE_BLADE_T = 7.0  # blade thickness (with rubber)
PADDLE_CLAMP_DEPTH = 35.0  # how deep the clamp grips the blade

# ---------------------------------------------------------------------------
# Helpers
# ---------------------------------------------------------------------------


def Z(mesh, dz):
    """Translate mesh along +Z by dz (mutates and returns)."""
    mesh.apply_translation([0, 0, dz])
    return mesh


def T(mesh, dx=0, dy=0, dz=0):
    mesh.apply_translation([dx, dy, dz])
    return mesh


def RX(mesh, deg):
    mesh.apply_transform(trimesh.transformations.rotation_matrix(np.radians(deg), [1, 0, 0]))
    return mesh


def RY(mesh, deg):
    mesh.apply_transform(trimesh.transformations.rotation_matrix(np.radians(deg), [0, 1, 0]))
    return mesh


def RZ(mesh, deg):
    mesh.apply_transform(trimesh.transformations.rotation_matrix(np.radians(deg), [0, 0, 1]))
    return mesh


def hole(d, h, sections=48):
    """A cylinder for boolean subtraction, centered on origin, axis = Z."""
    c = cylinder(radius=d / 2, height=h, sections=sections)
    return c


def servo_pocket():
    """A negative volume for an MG996R-style servo, centered on its body.
    Includes the body cavity (with print clearance + extra depth), ear cutouts,
    ear screw holes, and wire-relief channels at both narrow ends so the lead
    can exit whichever way the servo is oriented."""
    bw = SERVO_W + 2 * SERVO_CLEAR
    bd = SERVO_D + 2 * SERVO_CLEAR
    # taller box + lowered floor => the servo seats SERVO_EXTRA_DEPTH deeper
    body = box((bw, bd, SERVO_H + 20 + SERVO_EXTRA_DEPTH))
    body.apply_translation([0, 0, 10 - SERVO_EXTRA_DEPTH])
    ears = box((bw + 2 * SERVO_EAR_EXTENT, bd, SERVO_EAR_THICK + 1))
    ears.apply_translation([0, 0, SERVO_H / 2 - 13])  # roughly where the ears sit on the body
    parts = [body, ears]
    # Ear screw clearance holes (4)
    for sx in (-1, 1):
        for sy in (-1, 1):
            h = hole(SERVO_EAR_SCREW_D, 30)
            h.apply_translation(
                [
                    sx * SERVO_EAR_SCREW_SPACING_X / 2,
                    sy * SERVO_EAR_SCREW_SPACING_Y / 2,
                    SERVO_H / 2 - 13,
                ]
            )
            parts.append(h)
    # Wire-relief channels through both narrow ends, low on the body
    ch_len = 2 * (WALL + SERVO_EAR_EXTENT + 4)
    for sx in (-1, 1):
        ch = box((ch_len, 10.0, 24.0))  # >=5/16in (7.94mm); roomy enough for the connector
        ch.apply_translation([sx * SERVO_W / 2, 0, -13])
        parts.append(ch)
    # IMPORTANT: union the negatives into one clean manifold. Concatenating them
    # leaves overlapping internal faces that make the later CSG subtraction leave
    # an internal ledge at ear height (servo only seats halfway). Union fixes it.
    pocket = parts[0]
    for p in parts[1:]:
        pocket = pocket.union(p)
    return pocket


def bldc_mount_negatives():
    """Holes for an A2212-class motor: central shaft pass-through and a 4-screw X pattern.
    Returns a list of cylinder meshes oriented along Z, centered at origin."""
    cyls = []
    # Central shaft pass-through (slightly larger than shaft)
    cyls.append(hole(BLDC_SHAFT_D + 1.0, 40))
    # 4 mount screws on a bolt circle, X pattern (45° offsets)
    r = BLDC_MOUNT_BOLT_CIRCLE / 2.0
    for ang in (45, 135, 225, 315):
        c = hole(BLDC_MOUNT_SCREW_D, 40)
        c.apply_translation([r * np.cos(np.radians(ang)), r * np.sin(np.radians(ang)), 0])
        cyls.append(c)
    return cyls


# ---------------------------------------------------------------------------
# Part 1: Base plate
# ---------------------------------------------------------------------------


def make_base_plate():
    """Footprint that bolts to a heavy base. Holds J1 (yaw) servo pointing up.
    Also has a 608 bearing pocket on top center to take the radial load off
    the servo output shaft (the yaw bracket has a stub that rides in the
    bearing)."""
    plate_w = 110.0
    plate_d = 90.0
    plate_t = PLATE_T

    base = box((plate_w, plate_d, plate_t))
    base.apply_translation([0, 0, plate_t / 2])

    # Servo mount tower — a raised block in the middle that the servo drops into
    tower_w = SERVO_W + 2 * WALL + 2 * SERVO_EAR_EXTENT
    tower_d = SERVO_D + 2 * WALL
    tower_h = SERVO_H + 4  # a touch deeper so ears sit below the top surface
    tower = box((tower_w, tower_d, tower_h))
    tower.apply_translation([0, 0, plate_t + tower_h / 2])

    body = base.union(tower)

    # Carve out the servo pocket (centered, shaft poking up through the top)
    pocket = servo_pocket()
    pocket.apply_translation([0, 0, plate_t + tower_h / 2])
    body = body.difference(pocket)

    # 4 corner bolt-down slots (M4 clearance) for fastening to a heavy base
    for sx in (-1, 1):
        for sy in (-1, 1):
            h = hole(M4_CLEAR, plate_t * 3)
            h.apply_translation([sx * (plate_w / 2 - 8), sy * (plate_d / 2 - 8), plate_t / 2])
            body = body.difference(h)

    return body


# ---------------------------------------------------------------------------
# Part 2: Yaw bracket  (rides on J1 horn, holds J2)
# ---------------------------------------------------------------------------


def make_yaw_bracket():
    """U-shaped bracket: bottom face bolts to J1 servo horn. Vertical wall
    holds J2 (pitch servo) on its side, so J2's output shaft points horizontally."""
    bot_w = 60.0
    bot_d = 60.0
    bot_t = 6.0

    bottom = box((bot_w, bot_d, bot_t))
    bottom.apply_translation([0, 0, bot_t / 2])

    # Vertical wall — tall enough to hold the pitch servo on its long axis
    wall_w = bot_w
    wall_t = WALL + SERVO_D  # wall must be thick enough to contain the servo body
    wall_h = SERVO_W + 2 * WALL + 2 * SERVO_EAR_EXTENT
    wall = box((wall_w, wall_t, wall_h))
    wall.apply_translation([0, bot_d / 2 - wall_t / 2, bot_t + wall_h / 2])

    body = bottom.union(wall)

    # Servo-horn screw circle (4-screw pattern at small radius) — bolt onto J1 horn
    for ang in (0, 90, 180, 270):
        r = 7.0
        h = hole(M3_CLEAR, bot_t * 3)
        h.apply_translation([r * np.cos(np.radians(ang)), r * np.sin(np.radians(ang)), bot_t / 2])
        body = body.difference(h)
    # Center hole for servo shaft clearance
    body = body.difference(
        hole(6.0, bot_t * 3).apply_translation([0, 0, bot_t / 2]) or hole(6.0, bot_t * 3)
    )

    # Pocket the pitch servo into the wall (servo lies sideways, shaft pokes out -Y)
    pocket = servo_pocket()
    RX(pocket, 90)  # lay it on its side so shaft points +Y / -Y
    # After RX(90), the pocket's original Z axis becomes Y. Shift to embed in wall.
    pocket.apply_translation([0, bot_d / 2 - wall_t / 2 + 5, bot_t + wall_h / 2])
    body = body.difference(pocket)

    return body


# ---------------------------------------------------------------------------
# Part 3: Pitch bracket  (rides on J2 horn, holds BLDC + bearings)
# ---------------------------------------------------------------------------


def make_pitch_bracket():
    """L-shaped bracket. Short face bolts to J2 horn. Long face holds the BLDC
    coaxially, with a 608 bearing on each side for radial support of the swing arm.
    The swing arm sits OUTSIDE the bracket; the motor's shaft passes through one
    bearing and drives the arm hub. The other end of the arm hub is supported by
    the second bearing on a stub shaft for stability."""
    face_w = 70.0
    face_h = 50.0
    face_t = 6.0
    back_w = face_w
    back_h = 30.0
    back_t = 6.0

    face = box((face_w, face_t, face_h))
    face.apply_translation([0, 0, face_h / 2])

    back = box((back_w, back_h, back_t))
    back.apply_translation([0, back_h / 2 + face_t / 2, back_t / 2])

    body = face.union(back)

    # Back plate: 4-hole horn pattern for bolting to J2 horn
    for ang in (0, 90, 180, 270):
        r = 7.0
        h = hole(M3_CLEAR, back_t * 3)
        h.apply_translation([r * np.cos(np.radians(ang)), back_h / 2 + face_t / 2, back_t / 2])
        body = body.difference(h)
    # Center shaft clearance through back plate
    c = hole(6.0, back_t * 3)
    c.apply_translation([0, back_h / 2 + face_t / 2, back_t / 2])
    body = body.difference(c)

    # NOTE (2026-06-14 fix): the old code bored a 22.4mm bearing pocket 7.4mm deep
    # into a 6mm wall — it cut clean through and swallowed the 4 motor mount holes,
    # so printed brackets had NO way to bolt the motor on. We have no 608 bearing
    # anyway, so the motor mounts cantilevered: its X-mount cross bolts FLAT to this
    # face, shaft + bell point out the front, only the leads pass through the center.

    # Center pass-through for the motor leads (no bearing, no bell clearance needed)
    wire = cylinder(radius=BLDC_WIRE_HOLE_D / 2, height=face_t * 4, sections=48)
    RX(wire, 90)
    wire.apply_translation([0, 0, face_h / 2])
    body = body.difference(wire)

    # Motor X-mount screw circle — 4 holes matching the cross's OUTER (tip) holes.
    # M3 clearance; fasten with M3 screws + nuts on the back of the face.
    r = BLDC_XMOUNT_BOLT_CIRCLE / 2
    for ang in (45, 135, 225, 315):
        h = cylinder(radius=M3_CLEAR / 2, height=face_t * 4, sections=24)
        RX(h, 90)
        h.apply_translation(
            [r * np.cos(np.radians(ang)), 0, face_h / 2 + r * np.sin(np.radians(ang))]
        )
        body = body.difference(h)

    return body


# ---------------------------------------------------------------------------
# Part 4: Swing arm  (bolts to BLDC shaft, holds paddle clamp at the end)
# ---------------------------------------------------------------------------


def make_swing_arm():
    """A flat blade arm with a hub at one end (for the BLDC shaft + set screw)
    and a pair of paddle clamp screw bosses at the other end."""
    # Hub end
    hub_r = 14.0
    hub_h = SWING_ARM_T + 6.0
    hub = cylinder(radius=hub_r, height=hub_h, sections=64)
    hub.apply_translation([0, 0, hub_h / 2])

    # Arm shaft
    arm = box((SWING_ARM_W, SWING_ARM_LEN, SWING_ARM_T))
    arm.apply_translation([0, SWING_ARM_LEN / 2, SWING_ARM_T / 2])

    # Tip pad (where the paddle clamp mounts)
    tip_w = 35.0
    tip_d = 35.0
    tip_t = SWING_ARM_T + 2.0
    tip = box((tip_w, tip_d, tip_t))
    tip.apply_translation([0, SWING_ARM_LEN, tip_t / 2])

    body = hub.union(arm).union(tip)

    # Hub: shaft hole + radial set-screw
    shaft = hole(BLDC_SHAFT_D + 0.2, hub_h * 3)
    body = body.difference(shaft)
    set_screw = cylinder(radius=M3_TAP / 2, height=hub_r * 3, sections=24)
    RY(set_screw, 90)
    set_screw.apply_translation([0, 0, hub_h / 2])
    body = body.difference(set_screw)

    # Tip: 4 M3 holes for paddle clamp
    for sx in (-1, 1):
        for sy in (-1, 1):
            h = hole(M3_CLEAR, tip_t * 3)
            h.apply_translation([sx * 10, SWING_ARM_LEN + sy * 10, tip_t / 2])
            body = body.difference(h)

    # Lightening pockets to reduce inertia (the arm whips, mass at the tip hurts)
    n_pockets = 4
    pocket_w = SWING_ARM_W - 8
    spacing = (SWING_ARM_LEN - 60) / n_pockets
    for i in range(n_pockets):
        pocket_y = 30 + i * spacing + spacing / 2
        p = box((pocket_w, spacing * 0.6, SWING_ARM_T * 3))
        p.apply_translation([0, pocket_y, SWING_ARM_T / 2])
        body = body.difference(p)

    return body


# ---------------------------------------------------------------------------
# Part 5: Paddle clamp (two halves — print one, mirror in slicer for the other)
# ---------------------------------------------------------------------------


def make_paddle_clamp_half():
    """One half of the paddle clamp. Two halves bolt through the swing arm tip
    and squeeze the paddle blade between them."""
    w = 35.0
    d = PADDLE_CLAMP_DEPTH + 10
    t = 8.0

    body = box((w, d, t))
    body.apply_translation([0, 0, t / 2])

    # Channel for the paddle blade — half-depth on each clamp half
    chan = box((PADDLE_BLADE_W, PADDLE_CLAMP_DEPTH, PADDLE_BLADE_T / 2 + 0.5))
    # Run the channel along the width; we model "width" as X here.
    # The channel cuts into the +Z face, so it's offset upward.
    chan.apply_translation([0, 0, t - (PADDLE_BLADE_T / 4 + 0.25)])
    # But PADDLE_BLADE_W > w, so it'll exceed the part in X. That's fine — only
    # the intersection inside `body` matters for the subtraction.
    body = body.difference(chan)

    # 4 bolt holes matching the swing arm tip pattern
    for sx in (-1, 1):
        for sy in (-1, 1):
            h = hole(M3_CLEAR, t * 3)
            h.apply_translation([sx * 10, sy * 10, t / 2])
            body = body.difference(h)

    return body


# ---------------------------------------------------------------------------
# Build everything
# ---------------------------------------------------------------------------

PARTS = [
    ("01_base_plate.stl", make_base_plate),
    ("02_yaw_bracket.stl", make_yaw_bracket),
    ("03_pitch_bracket.stl", make_pitch_bracket),
    ("04_swing_arm.stl", make_swing_arm),
    ("05_paddle_clamp.stl", make_paddle_clamp_half),
]


def main():
    for fname, fn in PARTS:
        print(f"Building {fname} ...")
        m = fn()
        # Basic sanity: ensure watertight-ish before export
        print(f"  volume_ok={m.is_volume}  verts={len(m.vertices)}  faces={len(m.faces)}")
        out = os.path.join(HERE, fname)
        m.export(out)
        print(f"  wrote {out}")


if __name__ == "__main__":
    main()

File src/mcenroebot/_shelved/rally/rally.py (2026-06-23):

"""Top-level rally coordinator — wires predictor → aim → servo driver → swing."""

from __future__ import annotations

import logging
from collections.abc import AsyncIterator

from mcenroebot._shelved.ball import BallObservation
from mcenroebot._shelved.predictor import TrajectoryPredictor
from mcenroebot._shelved.swing import SwingController, SwingProfile
from mcenroebot.aim import AimController
from mcenroebot.clock import Clock
from mcenroebot.drivers import ServoDriver

__all__ = ["RallyCoordinator"]

_log = logging.getLogger(__name__)

# Default swing profile: 50 ms ramp-up / 50 ms hold / 50 ms ramp-down, peak=0.5.
_DEFAULT_SWING_PROFILE = SwingProfile(
    ramp_up_ms=50.0,
    hold_ms=50.0,
    ramp_down_ms=50.0,
    peak_throttle=0.5,
)


class RallyCoordinator:
    """Top-level rally controller. Wires:

        observation stream → TrajectoryPredictor → AimController → ServoDriver
                                                 → SwingController

    On each observation:
      1. Push the obs into the predictor.
      2. Predict the strike point (y, z, t) at x = strike_plane_x.
      3. If aim is reachable, write yaw + pitch to the servo driver.
      4. Decide whether to fire: when current time is within ``swing_latency_s``
         of the predicted impact_time, fire ONCE per arc.

    The "one fire per arc" rule is enforced via ``_last_fire_time`` — after a
    successful ``swing.fire()``, the coordinator refuses to fire again until at
    least ``rearm_min_interval_s`` seconds have elapsed.

    Swing arming (lazy):
        The coordinator calls ``swing.arm()`` lazily on the first ``step()`` call
        that produces a valid strike prediction.  This keeps construction simple and
        avoids arming the motor before any ball has been seen.  The coordinator
        NEVER disarms the swing — lifecycle management (disarm/re-arm between
        rallies) is the caller's responsibility.  If you need guaranteed cleanup,
        wrap the coordinator in an ``async with`` block on the ``SwingController``.

    Args:
        aim:                AimController for yaw/pitch computation.
        predictor:          TrajectoryPredictor to fit the trajectory.
        servo_driver:       ServoDriver to push servo commands to.
        swing:              SwingController for the actual paddle strike.
        clock:              Clock for ``now()`` (used to decide when to fire).
        strike_plane_x:     x-coordinate (m) of the strike plane. Default 0.0.
        swing_latency_s:    How long the swing takes from ``fire()`` to ball
                            contact. The coordinator fires this many seconds
                            BEFORE the predicted impact_time. Default 0.05.
        servo_yaw_channel:  PCA9685 channel for the yaw servo. Default 0.
        servo_pitch_channel:PCA9685 channel for the pitch servo. Default 1.
        swing_profile:      The SwingProfile to fire each strike with.
                            Default: ramp_up=50 ms / hold=50 ms / ramp_down=50 ms /
                            peak=0.5.
        rearm_min_interval_s:
                            How long the coordinator waits after a strike before it
                            will fire again. Default 0.5 s.
    """

    def __init__(
        self,
        aim: AimController,
        predictor: TrajectoryPredictor,
        servo_driver: ServoDriver,
        swing: SwingController,
        clock: Clock,
        strike_plane_x: float = 0.0,
        swing_latency_s: float = 0.05,
        servo_yaw_channel: int = 0,
        servo_pitch_channel: int = 1,
        swing_profile: SwingProfile | None = None,
        rearm_min_interval_s: float = 0.5,
    ) -> None:
        self._aim = aim
        self._predictor = predictor
        self._servo_driver = servo_driver
        self._swing = swing
        self._clock = clock
        self._strike_plane_x = strike_plane_x
        self._swing_latency_s = swing_latency_s
        self._servo_yaw_channel = servo_yaw_channel
        self._servo_pitch_channel = servo_pitch_channel
        self._swing_profile: SwingProfile = swing_profile or _DEFAULT_SWING_PROFILE
        self._rearm_min_interval_s = rearm_min_interval_s

        self._last_fire_time: float | None = None
        self._armed: bool = False

    async def step(self, obs: BallObservation) -> None:
        """Push one observation through the full pipeline.

        Steps:
          1. Add ``obs`` to the predictor.
          2. Query ``predict_strike`` — if None (too few obs or ball moving away),
             return early without touching servos or swing.
          3. Call ``aim.compute(impact_point)`` — if None (out of reach), log and
             return without servo writes or firing.
          4. Write yaw to ``servo_yaw_channel`` and pitch to ``servo_pitch_channel``.
          5. Decide whether to fire (timing + rearm guard).  If so, arm lazily then
             call ``swing.fire(swing_profile)``.
        """
        # Step 1: feed the observation to the predictor.
        self._predictor.add(obs)

        # Step 2: attempt a strike prediction.
        prediction = self._predictor.predict_strike(self._strike_plane_x)
        if prediction is None:
            return  # not enough observations, or ball not approaching

        # Step 3: compute servo angles.
        angles = self._aim.compute(prediction.impact_point)
        if angles is None:
            _log.debug("Impact point %s is out of reach — skipping", prediction.impact_point)
            return

        # Step 4: write servo angles.
        self._servo_driver.write_angle(self._servo_yaw_channel, angles.yaw_deg)
        self._servo_driver.write_angle(self._servo_pitch_channel, angles.pitch_deg)

        # Step 5: decide whether to fire.
        now = self._clock.now()
        fire_time = prediction.impact_time - self._swing_latency_s

        if now < fire_time:
            return  # still too early — don't fire yet

        # Enforce one-fire-per-arc via rearm guard.
        if self._last_fire_time is not None:
            elapsed_since_fire = now - self._last_fire_time
            if elapsed_since_fire < self._rearm_min_interval_s:
                return  # rearm interval not yet elapsed

        # Lazy arm: arm the swing on the first fire attempt.
        if not self._armed:
            self._swing.arm()
            self._armed = True

        self._last_fire_time = now
        await self._swing.fire(self._swing_profile)

    async def run(self, stream: AsyncIterator[BallObservation]) -> None:
        """Consume an async iterator of observations, calling ``step`` for each.

        Returns when the stream is exhausted.  Any exception raised by ``step``
        (including hardware faults from the swing controller) propagates
        immediately — the caller is responsible for deciding whether to restart
        or abort the rally loop.
        """
        async for obs in stream:
            await self.step(obs)

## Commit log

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2026-05-25 feat(aim): refactor Position3D, ServoAngles, and TurretGeometry to use Pydantic models for validation
2026-05-25 docs: add comprehensive README, implementation plan; move V2_PLAN to docs/
    - README.md: rewrite from single-line to comprehensive overview (how it works,
    hardware table, coordinate frame, status, quickstart, Pi deploy, coding
    standards, layout, gitflow).
    - docs/implementation-plan.md: actionable wave-by-wave build checklist derived
    from V2_PLAN.md, with module dependency graph and per-module acceptance
    criteria.
    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
2026-05-25 feat(drivers): add ServoDriver + BLDCDriver protocols, real + mock impls
    drivers/servo/{protocol,pca9685,mock}.py and drivers/bldc/{protocol,pca9685,mock}.py.
    Each sub-package exposes a runtime-checkable Protocol plus two concrete
    implementations: a real PCA9685-over-I2C driver (Pi only, lazy adafruit
    import) and an in-memory mock for unit tests.
    Mock drivers validate inputs the same way the real drivers do (angle range
    for servo; armed-state + throttle range for BLDC) so test assertions stay
    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
2026-05-25 feat(swing): add SwingController + SwingProfile open-loop control
    Open-loop BLDC throttle envelope (ramp-up / hold / ramp-down) driven at
    _TICK_MS=5 ms cadence; context manager guarantees driver disarm on exit.
2026-05-25 feat(calibrate): add EscCalibrator one-shot routine
    Implements the standard ESC throttle calibration sequence (max→min
    throttle with operator prompts) as a testable async class with
    try/finally disarm guarantee and FakeClock-compatible timing.
    Also suppresses Python 3.13 asyncio GC-timing ResourceWarnings that
    manifested when test_calibrate ran before test_clock alphabetically.
2026-05-25 feat(coordinator): wire predictor → aim → swing in RallyCoordinator
    Implements the top-level RallyCoordinator that connects the full
    V2 control pipeline: TrajectoryPredictor → AimController → ServoDriver
    → SwingController with lazy arming and one-fire-per-arc rearm guard.
    Adds 18 integration tests covering all specified behaviours.
2026-05-26 added 3d models
    [01_base_plate.stl, 02_yaw_bracket.stl, 03_pitch_bracket.stl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]
2026-05-26 fix(scripts): mypy null-safety for __doc__ in calibrate_camera
    The build_parser() helper read __doc__.splitlines()[0]; under strict
    mypy __doc__ is Optional[str], so the .splitlines() access fails.
    Guard with (__doc__ or '') so the script passes mypy strict.
    Also updates docs/implementation-plan.md §6 — the camera calibration
    script existed as of be3e7ef; flag the open question as resolved
    modulo actually running the calibration against the live webcam.
    [calibrate_camera.py]
2026-05-26 docs(v3): add V3_PLAN.md — defensive-competitive ping pong robot
    Defensive scope: robot returns balls competitively (flat trajectory,
    not lobs), chases via linear axis along table edge, runs a learned
    policy for swing decisions. Reuses entire V2 turret and software stack;
    adds closed-loop swing module, wrist servo, linear axis, and a
    three-layer policy stack (heuristic → analytical → RL/PPO via PyBullet).
    Budget envelope ~$500-$700 of incremental hardware. 8-wave build
    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
2026-06-08 adding new code
    [01_base_plate.stl, 02_yaw_bracket.stl]
2026-06-23 adding untracked files
    [01_base_plate.stl, 02_yaw_bracket.stl, 03_pitch_bracket.stl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]
2026-06-23 refactor(shelved): archive V3 rally stack to _shelved/
    Move the V3 return-rally pipeline (ball/, predictor/, swing/, and the
    RallyCoordinator) out of the active package surface into
    src/mcenroebot/_shelved/, so the feeder build only exposes
    feeder-relevant modules. Imports rewritten to mcenroebot._shelved.*;
    camera/ stays active (ball/ still depends on it). Tests move alongside
    their code under tests/_shelved/ and keep passing. The active
    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
2026-06-23 feat(launch): add LaunchController + ShotSpec/WheelCommand/LaunchGeometry value objects
    Wave 1 of the V4 feeder: pure-math two-wheel launch solver, the feeder
    analog of aim/. Maps a ShotSpec (speed, signed spin, spin-axis) to a
    WheelCommand (top_rpm, bottom_rpm, head_roll) via the mean/difference
    surface-speed model. Out-of-envelope shots (spin too high for the
    speed, or rpm over max_wheel_rpm) return None rather than raising.
    ThrottleMap converts wheel rpm to ESC throttle for the bldc layer.
    Frozen pydantic value objects throughout; stateless controller with
    injected LaunchGeometry. TDD; launch/ at 100% coverage, mypy clean.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
2026-06-23 feat(drivers): add feeder (escapement) and lift (auger) drivers with mocks
    Wave 2 of the V4 feeder. Two new GPIO-driver packages following the
    servo/bldc Protocol+real(lazy)+Mock pattern:
    - drivers/feeder: FeederDriver Protocol, Pca9685FeederDriver (CR servo,
    lazy adafruit_servokit), MockFeederDriver. Pure throttle_for_rate()
    mapping is extracted to mapping.py for off-Pi testing. v1 fire()
    raises NotImplementedError (index-endstop upgrade deferred).
    - drivers/lift: LiftDriver + HopperSensor Protocols, Pca9685LiftDriver
    (PWM->MOSFET), GpioHopperSensor (lazy RPi.GPIO), MockLiftDriver,
    MockHopperSensor.
    Adds RPi to the mypy missing-imports override. Documents the planned
    V4 PCA9685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
    [gpio.py, mapping.py, mock.py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]
2026-06-23 feat(drill): add Drill engine, AimStrategy Protocol, FixedPatternStrategy
    Wave 3 of the V4 feeder — the behavior layer. A Drill combines a launch
    ShotSpec, an AimStrategy, and a cadence into an iterator of Shot. The
    AimStrategy Protocol is the pluggable seam for vision placement (Wave 6).
    FixedPatternStrategy implements four vision-free patterns over a
    TableTarget region: static, oscillate (L/R extremes), random (uniform
    lateral, drill-seeded), and figure8 (1:2 Lissajous over depth x width).
    All randomness flows from one seed carried in DrillContext, so a fixed
    seed yields an identical Shot sequence.
    Pure logic, no hardware; drill/ at 100% coverage, mypy clean, 440 passed.
    Co-Authored-B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
2026-06-23 feat(coordinator): add FeederCoordinator wiring drill -> launch + aim + feeder + lift
    Wave 4 of the V4 feeder. FeederCoordinator is a periodic (not real-time)
    scheduler: per shot it computes the WheelCommand (skip+log if out of
    envelope), the pan/tilt angles (skip+log if unreachable), commands the
    head-roll + pan/tilt servos and the two wheel ESCs, settles, releases a
    ball (set_rate v1 or fire() index-upgrade), runs the auger unless the
    hopper is full, then waits out the cadence. A try/finally guarantees
    wheels zeroed+disarmed, feeder stopped, and auger off on any exit.
    Reuses AimController with arm_length_m as the placement range. Does not
    import the shelved V3 stack. Mock-tested with Fake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
2026-06-24 feat(scripts): add calibrate_feeder and calibrate_launch bring-up scripts
    Wave 5 of the V4 feeder. Two PEP 723 standalone scripts (isolated deps,
    same pattern as calibrate_camera.py; no runtime-dep pollution):
    - calibrate_feeder.py: sweeps CR-servo throttle, counts balls/min, fits
    the linear throttle_per_bpm factor for Pca9685FeederDriver.
    - calibrate_launch.py: from measured landing range (range->exit speed via
    projectile motion) and an optional video-measured spin, backs out
    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
2026-06-24 feat(player): add PlayerDetector + VisionPlacementStrategy for open-court targeting
    Wave 6 of the V4 feeder — the easy, forgiving vision slice (player side
    detection in the 1-2 s feed interval; no incoming-ball 3D tracking).
    - player/: PlayerPosition value object, PlayerDetector Protocol,
    SimpleBlobDetector (threshold + largest-contour centroid -> lateral
    offset; cv2 is a core dep so it's unit-tested with synthetic frames),
    MockPlayerDetector.
    - drill.VisionPlacementStrategy: implements AimStrategy, aims the next
    ball to the side opposite the player; defers to a fixed-pattern
    fallback below a confidence threshold. Drops in behind the AimStrategy
    Protocol with no change to laun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
    [mock.py, protocol.py]
2026-06-24 docs(v4): add hardware bring-up checklist for the remaining live phase gates
    Consolidates the Wave 5/6 operator runbook: mechanical de-risk, Pi setup,
    channel map + power budget, calibration script invocations, the two live
    phase gates, and the post-gate merge to develop. The software is complete;
    this is the checklist for the hardware-only remainder.
    Claude-Session: https://claude.ai/code/session_01UaY5VM2zKKWiWEuUbDMMQY
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2026-06-25 docs: update CLAUDE.md Gitflow state to the V4 feeder branch
    The Gitflow 'current state' line still described the abandoned V2
    feature/aim -> feature/v2-control flow and pointed at the V2
    implementation-plan.md. Replace it with the actual state:
    feature/v4-feeder carries all committed software waves and merges to
    develop after the Wave 5 hardware gate (per docs/v4-bringup-checklist.md).
    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
2026-06-25 assets(3d-models): add V4 feeder STLs, archive V2 paddle models
    Mirror the V4 pivot in the CAD assets: add the feeder parts (escapement
    disk, hopper cone, auger screw + tube, launch wheel) and the
    generate_feeder_parts.py generator; move the V2 paddle/turret STLs into
    docs/3d-models/archive/.
    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
    [01_base_plate.stl, 02_yaw_bracket.stl, 03_pitch_bracket.stl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]
